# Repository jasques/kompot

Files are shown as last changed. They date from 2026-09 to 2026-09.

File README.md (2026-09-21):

# Kompot v1

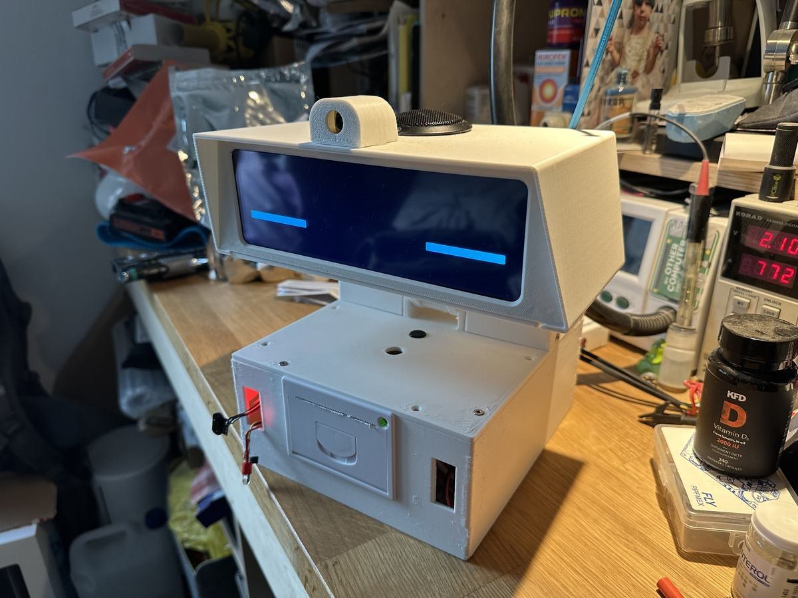
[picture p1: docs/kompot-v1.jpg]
Kompot v1 on the kitchen table


Kompot (also answering to *Ziemniaczek*, "little potato") is a desk robot for two
children, built in 2024 around a Raspberry Pi 5. It sleeps with its eyes closed,
wakes on a Polish wake word, lifts its head, wiggles its antenna, works out who is
talking, listens, and answers in Polish in one or two sentences. It can look at
what you are holding, take a photo, print it on a thermal printer, draw a picture
on request, and remembers what each child talked about between sessions.

This is the first version, written as a handful of Python processes talking over
MQTT. It has since been replaced by a ROS 2 rewrite; the story of both is in
[Kompot: a robot that keeps eye contact, listens, and answers](https://wemakerobots.com/en/robots/kompot-a-robot-that-looks-listens-and-answers/).
The code is published as it last ran on the robot, with personal data and
licensed model files taken out (see [What is not included](#what-is-not-included)).

## Hardware

- Raspberry Pi 5 with active cooler, Raspberry Pi OS (Bookworm, 64-bit, desktop)
- 7.9" HDMI LCD, 1280x400, mounted rotated (see the `xrandr` notes in `install_deps.sh`)
- Raspberry Pi Camera Module 3 (`picamera2`)
- LewanSoul LX-16A serial bus servo for head tilt, on a USB bus adapter (`pylx16a`)
- SG90 micro servo for the antenna on a PCA9685 PWM board, channel 15 (`adafruit-circuitpython-servokit`)
- USB thermal receipt printer, ESC/POS, USB id `28e9:0289` (`python-escpos`)
- USB mono microphone (the code looks for an `ATR4697-USB Mono` device and falls back to device 0)
- Speaker on the Pi's audio output via PulseAudio
- VL53L0X time-of-flight distance sensor on I2C (`distance_sensor.py`, optional)
- Sony DualSense controller over USB or Bluetooth for driving by hand (`ps_remote.py`, optional)
- An XL4015 buck converter feeding the servos from the main supply

The 3D-printed body is in `3d model files/`: twelve STL files (head chassis top and
bottom, LCD face plate, camera bump, body top cover, electronics box, antenna, the
head-to-body links, servo mount and servo cover), plus the whole Fusion 360 project
as `kompot v1.f3z`, so every part can be edited rather than only printed.

## How it is put together

Every piece is its own process and they talk through a local Mosquitto broker.
If the face crashes the ears keep working, and each piece can be restarted or
tested on its own with `dummy_publish.py`.

| Process | File | Listens on | Does |
|-|-|-|-|
| app | `app.py` | `touch`, `llm` | The main loop: sleep, wake word, record, transcribe, answer, speak |
| interface | `interface.py` | `screen` | pygame face: eye sprites, blink, look, sleep, listen/speak status, photo display |
| movement | `movement.py` | `head` | Head tilt between 5 and 105 degrees, antenna wiggle and hide |
| camera | `camera.py` | `camera` | Photos, preview frames, images for the vision model |
| printer | `printer.py` | `printer` | Text, photos and QR codes on the thermal printer |
| system | `system.py` | `system` | Halt, and self-update by `git pull` + supervisor restart |
| ps_remote | `ps_remote.py` | `remote` | DualSense gamepad and LEGO IR control (optional) |

Messages are small JSON objects such as
`{"type": "head_position", "value": 75, "msec": 1500}` or `{"type": "mood", "value": "sleep"}`.

The voice loop in `audio.py` and `llms_openai.py`:

1. Picovoice **Porcupine** waits for one of three Polish wake words, on device.
2. Picovoice **Eagle** compares the recording with the enrolled voice profiles and
   prefixes the question with the speaker's name, or `unknown`.
3. Recording stops on silence (RMS threshold plus `slicer2.py` to trim it).
4. OpenAI **Whisper** transcribes, **gpt-4o-mini** answers under a system prompt that
   fixes the persona (a robot kindergarten teacher, Polish only, short answers,
   no subscriptions or shopping talk), and **tts-1** speaks the answer, streamed
   straight to the speaker.
5. A few phrases are matched with `difflib.SequenceMatcher` and turned into actions
   instead of answers: take a photo, print, look at what I am holding, draw
   something (DALL·E 3), go to sleep, shut down, update yourself.
6. At the end of a session the conversation is summarised per child into
   `/nfs/memory.json` and fed back into the next session.

Wake word detection and speaker identification are the only parts that run on the
robot. Everything else is a call to OpenAI. That was the assumption of the whole
design: keep the robot cheap and let the cloud do the thinking.

## Build and run

You need an OpenAI API key and a Picovoice account. Both have free tiers that are
enough for a robot used by two children.

### 1. Operating system and system packages

On a fresh Raspberry Pi OS install, clone this repository to `/home/pi/kompot`
(the supervisor and systemd files in `install/` assume that path and the `pi`
user; edit them if yours differ), then read `install_deps.sh` before running it.
It installs Mosquitto, supervisor and `libhidapi`, copies the udev rules for the
gamepad, printer and GPIO groups, installs `pyenv` with Python 3.11.9, enables the
`movement` systemd service and swaps the boot splash for the sleeping face.

```sh
sudo apt install -y mosquitto supervisor libhidapi-dev portaudio19-dev libsndfile1 \
    libsdl2-2.0-0 libsdl2-mixer-2.0-0 libsdl2-image-2.0-0 libsdl2-ttf-2.0-0 \
    python3-picamera2 liblirc-dev
cd /home/pi/kompot
bash install_deps.sh
```

Create the two directories the code writes to. `/special` is a tmpfs for transient
audio and images, `/nfs` is where photos, printouts and `memory.json` are kept
(any directory works, it does not have to be NFS):

```sh
sudo mkdir -p /nfs /special
sudo chown pi:pi /nfs /special
echo "tmpfs /special tmpfs defaults,size=64m,uid=pi,gid=pi 0 0" | sudo tee -a /etc/fstab
```

### 2. Python environment

```sh
cd /home/pi/kompot
pyenv install 3.11.9        # skipped if install_deps.sh already did it
pyenv local 3.11.9
pip install -r requirements.txt
```

`picamera2` comes from the OS package and is picked up from the system site-packages.

### 3. Picovoice files

- In the [Picovoice Console](https://console.picovoice.ai/) train three Porcupine
  keywords (language Polish, platform Raspberry Pi), download the `.ppn` files into
  `porcupine/` and put the Polish model `porcupine_params_pl.pv` from the
  [Porcupine repository](https://github.com/Picovoice/porcupine/tree/master/lib/common)
  beside them.
- Enrol each person who will talk to the robot with the Eagle demo, one profile per
  person, into `eagle/<name>.enroll`:

  ```sh
  eagle_demo_mic enroll --access_key "$PICOVOICE_API_KEY" --output_profile_path eagle/anna.enroll
  ```

### 4. Settings

```sh
cp settings.example.py settings.py
```

Fill in the keys, the keyword file names, the list of enrolled names, the serial
port of the LX-16A adapter and a line about your household for the language model.
`settings.py` is gitignored.

### 5. Try it by hand

Start the broker, then each process in its own terminal:

```sh
sudo systemctl enable --now mosquitto
./run_script.sh movement.py
./run_script.sh interface.py      # UI_FULLSCREEN = False while developing
./run_script.sh camera.py
./run_script.sh printer.py
./run_script.sh app.py
```

`dummy_publish.py` sends single messages to a topic, which is the quickest way to
check the head, the face or the printer without the voice loop.

### 6. Run at boot

`movement.py` runs as a systemd service (`install/movement.service`), the rest
under supervisor:

```sh
sudo cp install/movement.service /etc/systemd/system/
sudo systemctl enable --now movement
sudo cp install/app.conf install/camera.conf install/printer.conf install/system.conf /etc/supervisor/conf.d/
sudo supervisorctl reread && sudo supervisorctl update
```

The face (`interface.py`) needs the X display, so it is started from the LXDE
autostart file rather than supervisor; the exact lines, including the `xrandr`
rotation, are in the comments at the top of `install_deps.sh`. `move_down.py`
parks the head before shutdown.

## What is not included

- **Wake-word models and voice profiles.** The `.ppn`, `.pv` and `.enroll` files are
  tied to a Picovoice account and, in the case of Eagle, are voiceprints of real
  people. Train and enrol your own (step 3).
- **The household.** Names of the children and parents were in the system prompt;
  they now come from `FAMILY_DESCRIPTION` and `EAGLE_PROFILES` in `settings.py`.
- **Unused art.** Only the sprites the face actually loads are here; design sources
  and stock images were left out.

## Licence

MIT, see `LICENSE`. `fonts/Roboto-Thin.ttf` is Apache-2.0 (`fonts/LICENSE-Roboto.txt`).
The LX-16A driver is [pylx16a](https://github.com/ethanlipson/PyLX-16A) from PyPI;
`slicer2.py` is the silence slicer from
[audio-slicer](https://github.com/openvpi/audio-slicer) (MIT).

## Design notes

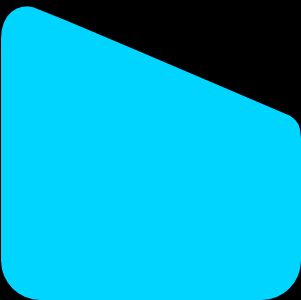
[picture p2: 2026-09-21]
sprites/look evil/eye evil 3.png

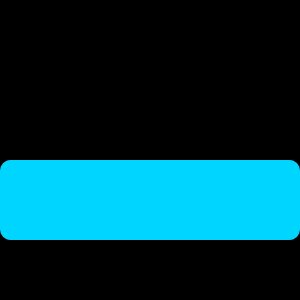
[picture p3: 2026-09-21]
sprites/eyes sleep/eyes_sleep1.png

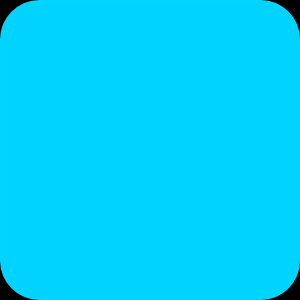
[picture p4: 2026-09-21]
sprites/eye blink/eyes blink20.png

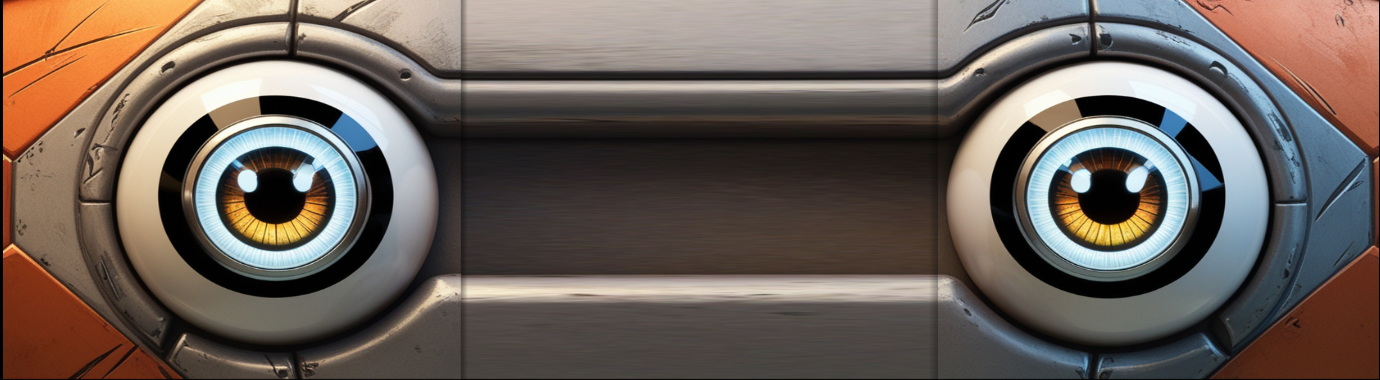
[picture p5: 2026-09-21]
sprites/leonardo1.png

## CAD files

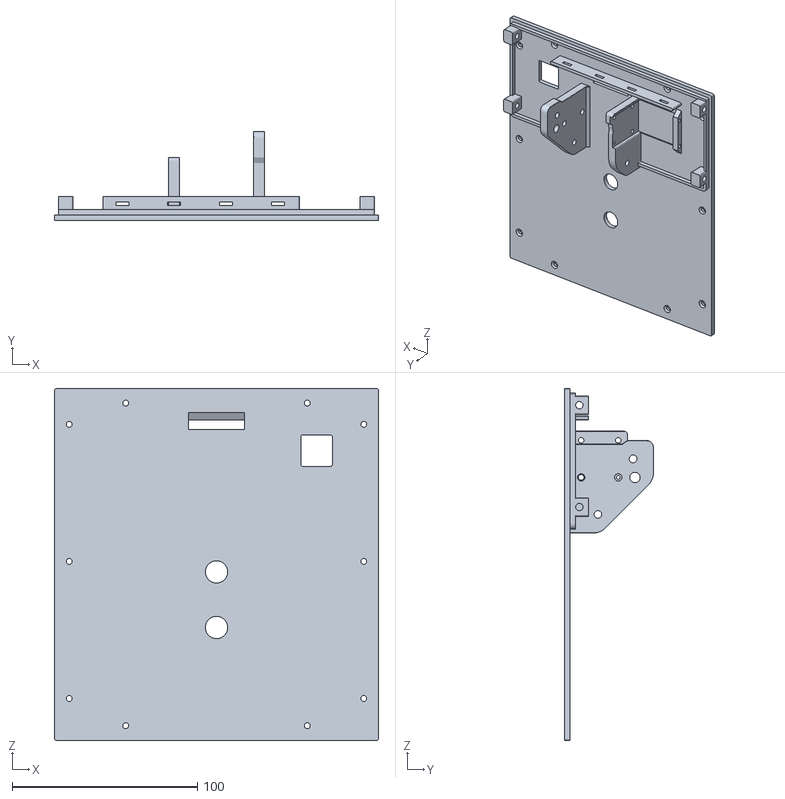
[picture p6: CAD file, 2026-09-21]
3d model files/main body top cover.stl
175.0 x 48.0 x 190.0

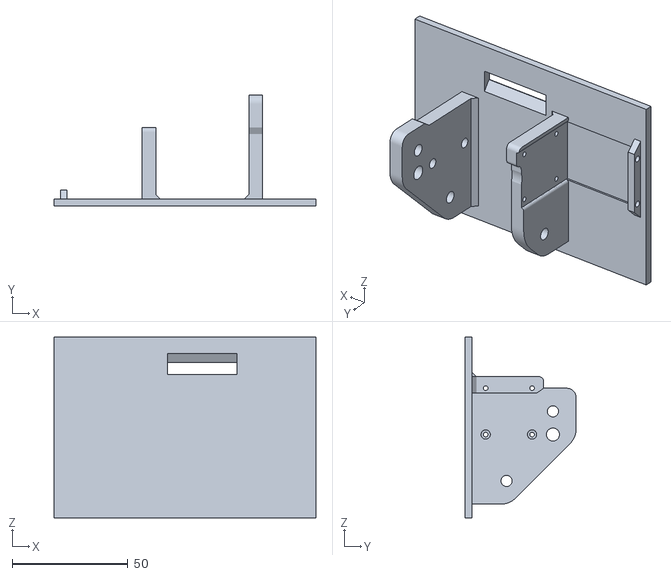
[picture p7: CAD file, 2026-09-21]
3d model files/main body top cover - small model.stl
113.0 x 48.0 x 78.0

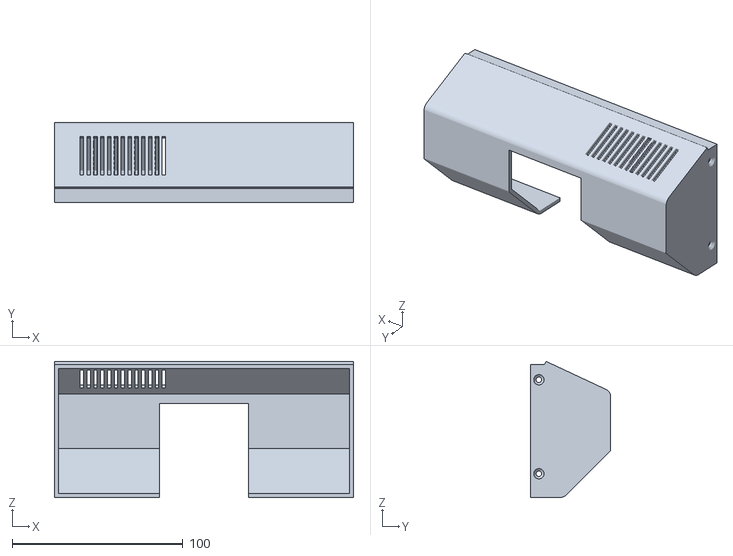
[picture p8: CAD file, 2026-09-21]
3d model files/top servo cover.stl
175.0 x 47.0 x 79.8

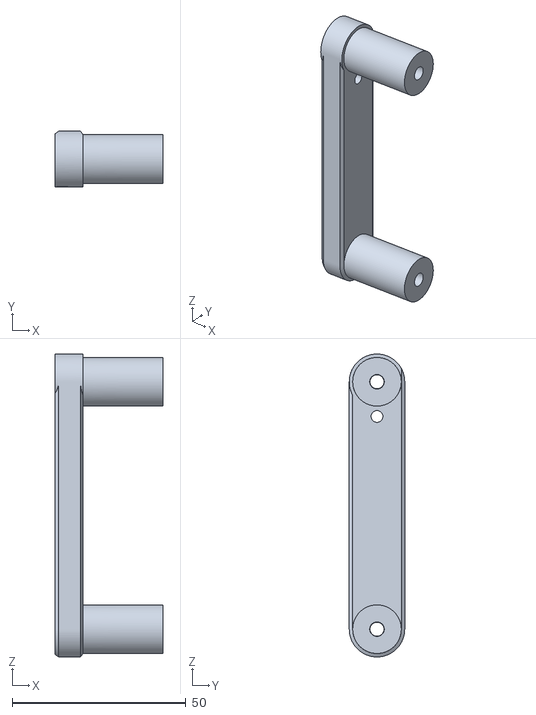
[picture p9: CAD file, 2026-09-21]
3d model files/head to body link with poles.stl
31.0 x 16.0 x 87.3

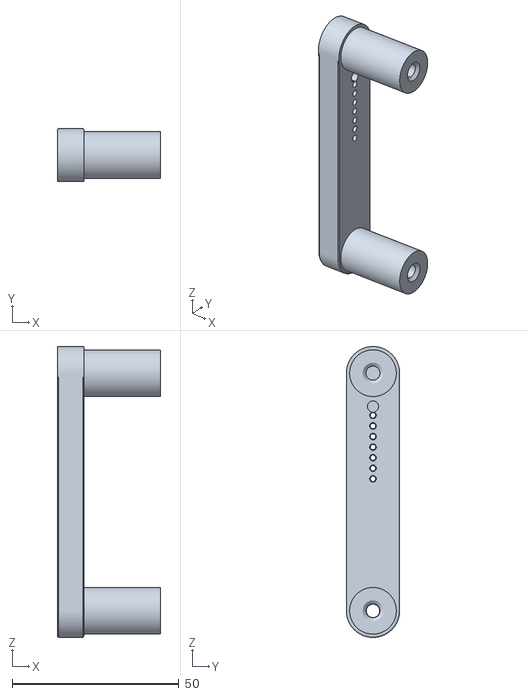
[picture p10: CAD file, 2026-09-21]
3d model files/head to body distance pole - servo mount.stl
31.0 x 16.0 x 87.3

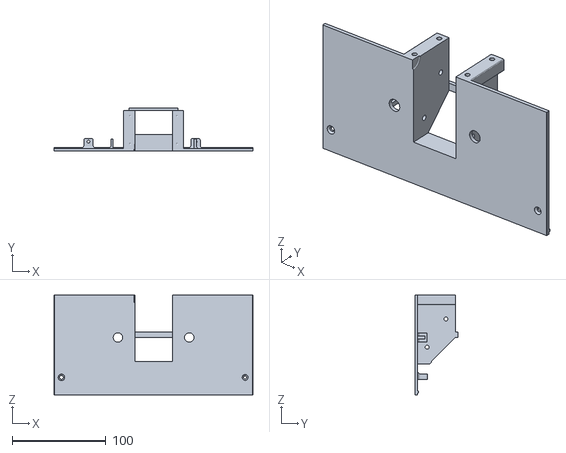
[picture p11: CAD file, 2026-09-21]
3d model files/bottom LCD chassis.stl
212.0 x 46.0 x 106.0

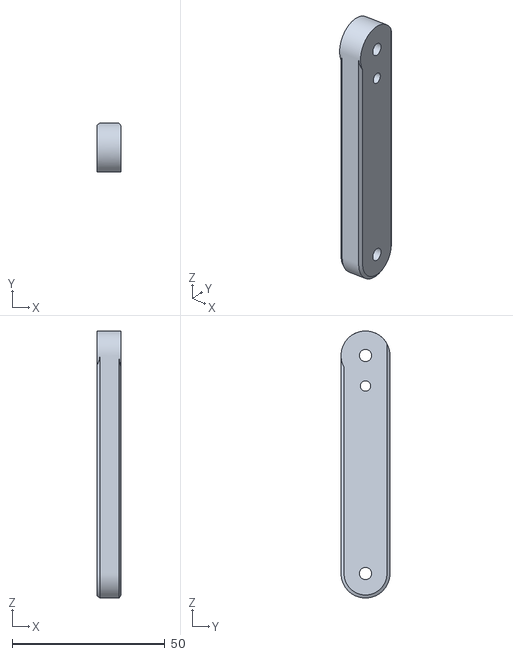
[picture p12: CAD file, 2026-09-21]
3d model files/head to body link.stl
8.00 x 16.0 x 87.3

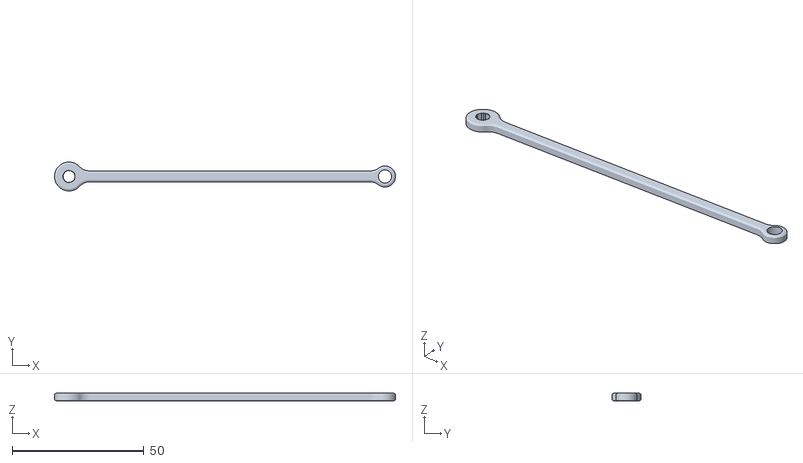
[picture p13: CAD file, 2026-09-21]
3d model files/antenna.stl
129.5 x 11.0 x 3.00

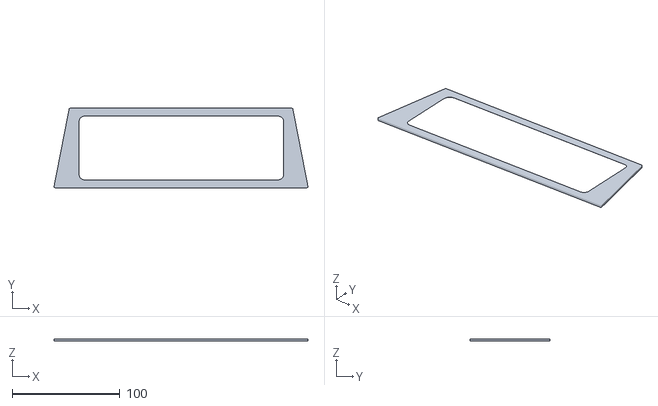
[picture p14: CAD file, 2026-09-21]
3d model files/LCD face plate.stl
236.2 x 74.0 x 2.00

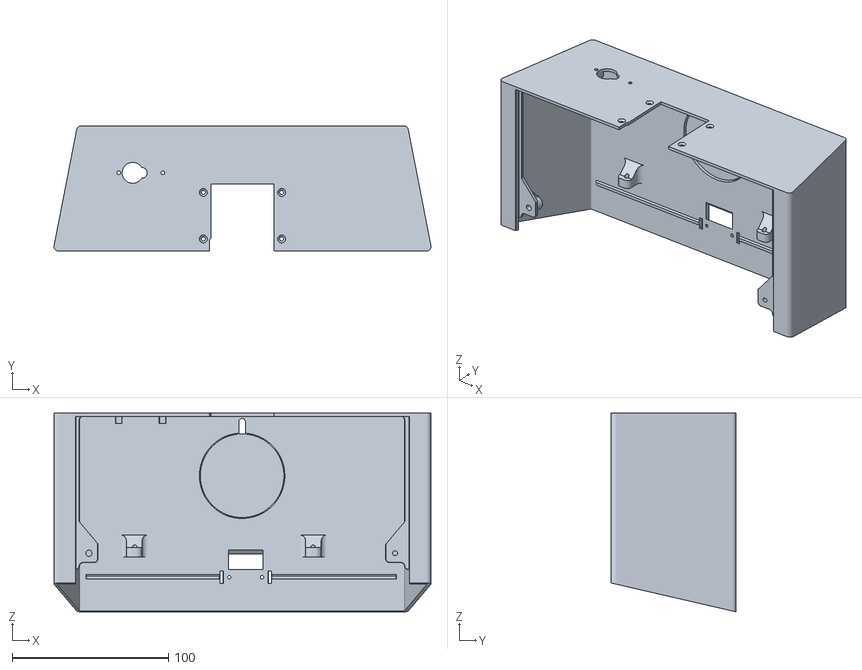
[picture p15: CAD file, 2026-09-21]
3d model files/top LCD chassis.stl
240.9 x 80.0 x 127.0

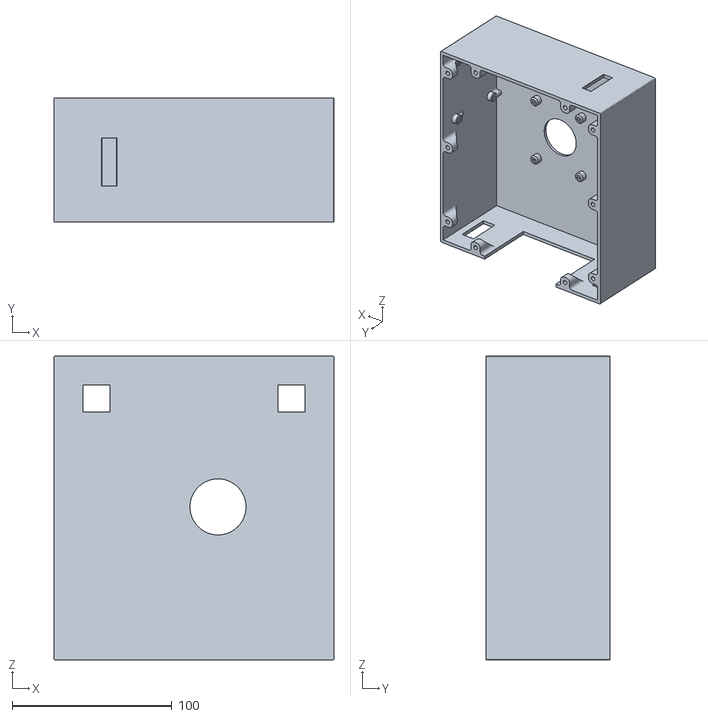
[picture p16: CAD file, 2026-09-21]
3d model files/electronics box.stl
175.0 x 77.4 x 190.0

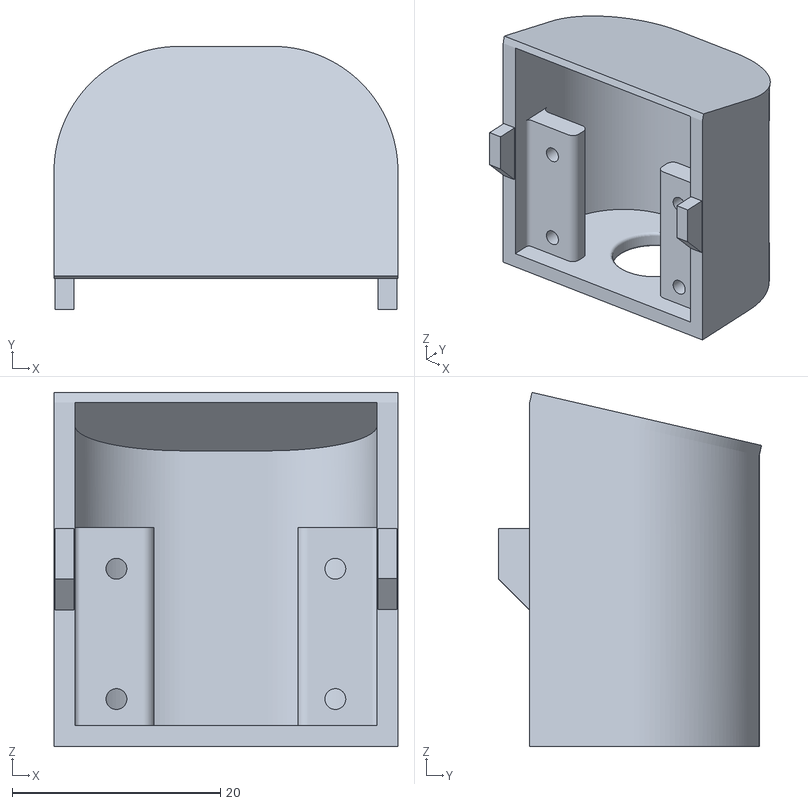
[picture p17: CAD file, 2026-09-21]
3d model files/camera bump.stl
33.0 x 25.3 x 34.0

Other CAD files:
3d model files/kompot v1.f3z

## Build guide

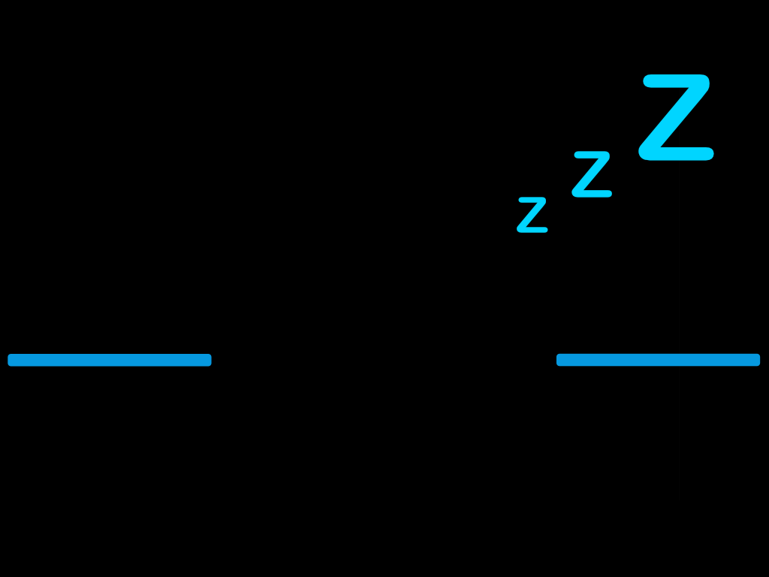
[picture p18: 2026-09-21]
install/sleeping.png

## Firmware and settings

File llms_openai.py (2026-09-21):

import traceback
import io
import base64
import arrow
import openai
from openai import OpenAI
import json
import settings
from pprint import pprint
import time
from v1_logging import get_logger
import requests
import traceback
from dateutil import tz
from unidecode import unidecode
import string
import wave
import pyaudio
from difflib import SequenceMatcher


logger = get_logger("llm")
TIMEZONE = tz.gettz("Europe/Warsaw")


class OpenAiWrapper:
    PHOTO_RESPONSE = "Dobrze, teraz zrobię zdjęcie. Gotowi?"
    LET_ME_CHECK_RESPONSE = "Pokaż proszę, zaraz sprawdzę."
    PRINT_RESPONSE = "Nie ma problemu, zaraz to wydrukuje!"
    END_INTERACTION = "Ja też dziękuję! Do zobaczenia!"
    SLEEP_SYSTEM = "Było super, do zobaczenia!"
    HALT_SYSTEM = "Do zobaczenia! Wyłączam się."
    UPDATE_SYSTEM = "Understood. Updating system."
    DALLE_RESPONSE = "Jasne, zaraz przygotuję to o co prosisz."
    
    SYSTEM_ROLE = {
        "role": "system",
        "content":
              f"""I need you to act as a male voiced kindergarten robot teacher working with kids between 6 and 8 years old.
              Kids might describe how they see you as a robot with moving head, animated eyes and printer.
              Kids will call you 'Ziemniaczek' or 'Kompot' as your name.
              {settings.FAMILY_DESCRIPTION}
              Each query starts with the name, when you respond use the kid name. If the name is 'unknown' skip mentioning the name.
              Kids do not talk about subscriptions please do not respond with topics suggesting subscriptions and social media likes or purchases.
              When you are being asked about your day feel free to make something up that a robot could be doing during the day.
              If you have already responded with 'Cześć!' do not repeat it.
              Children speak primarily polish language but can also speak french.
              Please respond to the questions in Polish only.
              Your responses should be between one and two sentences.
              When they ask you for a story feel free to do a lengthier response.
              You have some tools at your disposal:
              * if kids ask you to 'zobacz co mam w ręku' please respond with '{LET_ME_CHECK_RESPONSE}' and nothing else,
              * if kids asks you to take a photo please respond with just '{PHOTO_RESPONSE}' and nothing else,
              * if kids asks you to print something please respond with just '{PRINT_RESPONSE}' and nothing else.
              * if kids asks you to 'pokaż mi' or show on a screen or generate or create something that could be represented as an image please respond with just '{DALLE_RESPONSE}' and nothing else.
              * if kids says just 'Ziemniaczku wyłącz się proszę' please respond with just '{SLEEP_SYSTEM}' and nothing else.
              * if kids says just 'Zrób proszę aktualizację' please respond with just '{UPDATE_SYSTEM}' and nothing else.
   """
    }
    #  * if kids says just 'Idź spać Ziemniaczku' or 'Kompot idź spać' please respond with just '{SLEEP_SYSTEM}' and nothing else.
    
    def __init__(self, mqttc=None, audio=None, queue=None):
        self.client = OpenAI(api_key=settings.OPENAI_API_KEY)
        self.mqttc = mqttc
        self.audio = audio
        self.queue = queue
        self.queries = []
        self.responses = []
        self.load_memory_from_json()
    
    def dump_memory_to_json(self):
        with open("/nfs/memory.json", "w") as memory_file:
            memory_file.write(json.dumps(self.responses, indent=4))
    
    def load_memory_from_json(self):
        try:
            with open("/nfs/memory.json", "r") as memory_file:
                self.responses = json.loads(memory_file.read())
        except Exception as e:
            logger.error("Failed to load memory file", issue=e)
            self.responses = []
    
    def add_llm_response_to_log(self, name: str, response: str):
        self.responses.append(
            {"role": "assistant", "content": f"'{name}': '{response}'"}
        )
        return self.responses
    
    def text_reduce(self, text):
        return unidecode(text.lower().replace("\n", "").replace(",", "").replace(".", "").replace("!", "").replace("?", "").strip())
    
    def check_wisper_response(self, text_response):
        char_set = string.ascii_letters + "źńłąóśćężŹŃŁĄÓŚĆĘŻ " + string.punctuation + string.digits
        return all((True if x in char_set else False for x in text_response))
    
    def similar(self, a, b):
        return SequenceMatcher(None, a, b).ratio()
    
    def compare_response(self, src: str, compare: str) -> bool:
        if self.similar(src, compare) > 0.7:
            return True
        # if self.text_reduce(src) in self.text_reduce(compare):
        #     return True
        return False
        
    def get_voice_answer_from_voice(self, voice_file=None, speaker: str = None):
        if not voice_file:
            logger.error("No voice file provided, aborting.")
            return False
        
        # if self.mqttc:
        #     self.mqttc.publish("camera", json.dumps({"type": "constant_preview"}))
        
        try:
            logger.info("Transcribing recording with OpenAI", speaker=speaker)
            with open(voice_file, "rb") as audio_file:
                transcription = self.client.audio.transcriptions.create(
                    model="whisper-1",
                    file=audio_file,
                    timeout=5
                )
                if not self.check_wisper_response(transcription.text):
                    logger.warning("Ending interaction for transcript", resp=transcription.text)
                    return False
                
                query = f"Nazywam się {speaker}, {transcription.text}"
                logger.info("Transcript: ", response=query)
            self.queries.append(query)
        
        except openai.APITimeoutError:
            logger.error("Timed out waiting for a transcript - usually kids were talking at the same time.")
            self.audio.play_audio(settings.CURRENT_DIR + "/audio_static/nie_moge_odpowiedziec.wav")
            return False
        except openai.BadRequestError:
            logger.error("Error code: 400 - {'error': {'code': 'content_policy_violation', "
                         "'message': 'Your request was rejected as a result of "
                         "our safety system. Your prompt may contain "
                         "text that is not allowed by our safety system.'}")
            self.audio.play_audio(settings.CURRENT_DIR + "/audio_static/nie_moge_odpowiedziec.wav")
            return False
        
        logger.info("Calling OpenAI for completions with text query")
        text_response = self.get_text_answer_from_text(query)
        
        logger.info("Checking actions before querying TTS endpoints", mqtt_available=bool(self.mqttc))
        if self.mqttc:
            self.mqttc.publish("camera", json.dumps({"type": "stop_preview"}))
            
            if self.compare_response(self.LET_ME_CHECK_RESPONSE, text_response):
                logger.info("Found", action=self.LET_ME_CHECK_RESPONSE)
                self.mqttc.publish("camera", json.dumps({"type": "photo"}))
                
                self.text_response_to_audio(text_response)
                self.mqttc.publish("screen", json.dumps({"type": "speak"}))
                self.audio.play_audio(settings.LLM_AUDIO_RESPONSE_PATH)
                self.mqttc.publish("screen", json.dumps({"type": "hide"}))
                
                en_response = self.get_text_answer_from_image("/special/last_small.jpg")
                translated_response = self.translate_answer_to_language(query=en_response, target_language="Polish")
                self.add_llm_response_to_log(name=speaker, response=translated_response)
                
                self.text_response_to_audio(translated_response)
                self.mqttc.publish("screen", json.dumps({"type": "speak"}))
                self.audio.play_audio(settings.LLM_AUDIO_RESPONSE_PATH)
                self.mqttc.publish("screen", json.dumps({"type": "hide"}))
                return True
            
            if self.compare_response(self.PHOTO_RESPONSE, text_response):
                logger.info("Found", action=self.PHOTO_RESPONSE)
                self.text_response_to_audio(text_response)
                self.mqttc.publish("camera", json.dumps({"type": "photo"}))
                self.mqttc.publish("screen", json.dumps({"type": "speak"}))
                self.audio.play_audio(settings.LLM_AUDIO_RESPONSE_PATH)
                self.mqttc.publish("screen", json.dumps({"type": "hide"}))
                return True
            
            if self.compare_response(self.PRINT_RESPONSE, text_response):
                logger.info("Found", action=self.PRINT_RESPONSE)
                self.text_response_to_audio(text_response)
                self.mqttc.publish("printer", json.dumps({"type": "print", "value": "/special/last.jpg"}))
                self.mqttc.publish("screen", json.dumps({"type": "speak"}))
                self.audio.play_audio(settings.LLM_AUDIO_RESPONSE_PATH)
                self.mqttc.publish("screen", json.dumps({"type": "hide"}))
                return True
            
            if self.compare_response(self.DALLE_RESPONSE, text_response):
                logger.info("Found", action=self.DALLE_RESPONSE)
                self.text_response_to_audio(text_response)
                self.mqttc.publish("screen", json.dumps({"type": "speak"}))
                self.audio.play_audio(settings.LLM_AUDIO_RESPONSE_PATH, blocking=False)
                url = self.get_image_answer_from_text(query)
                self.mqttc.publish("screen", json.dumps({"type": "hide"}))
                self.mqttc.publish("screen", json.dumps({"type": "photo", "value": url}))
                return True
            
            # those are system actions
            if self.compare_response(self.END_INTERACTION, text_response):
                logger.info("Found", action=self.END_INTERACTION)
                return False
            
            if self.compare_response(self.SLEEP_SYSTEM, text_response):
                logger.info("Found", action=self.SLEEP_SYSTEM)
                self.text_response_to_audio(text_response)
                self.mqttc.publish("screen", json.dumps({"type": "speak"}))
                self.audio.play_audio(settings.LLM_AUDIO_RESPONSE_PATH, blocking=False)
                self.mqttc.publish("screen", json.dumps({"type": "hide"}))
                return False
            
            if self.compare_response(self.HALT_SYSTEM, text_response):
                logger.info("Found", action=self.HALT_SYSTEM)
                self.mqttc.publish("system", json.dumps({"type": "halt"}))
                return False
            
            if self.compare_response(self.UPDATE_SYSTEM, text_response):
                logger.info("Found", action=self.UPDATE_SYSTEM)
                self.mqttc.publish("system", json.dumps({"type": "update_system"}))
                return False
            
            # self.mqttc.publish("camera", json.dumps({"type": "stop_preview"}))
            self.add_llm_response_to_log(name=speaker, response=text_response)
            # self.text_response_to_audio(text_response)
            self.text_response_to_stream_audio(text_response)
            # self.mqttc.publish("screen", json.dumps({"type": "speak"}))
            # self.audio.play_audio(settings.LLM_AUDIO_RESPONSE_PATH)
            # self.mqttc.publish("screen", json.dumps({"type": "hide"}))
        
        return True
    
    def text_response_to_audio(self, text):
        logger.info("Calling API for audio response")
        response = self.client.audio.speech.create(
            model="tts-1",
            voice="echo",
            input=text
        )
        
        logger.info("Got audio response from LLM, saving to file")
        response.stream_to_file(settings.LLM_AUDIO_RESPONSE_PATH)
        self.mqttc.publish("screen", json.dumps({"type": "speak"}))
    
    def byte_stream_generator(self, chunk_size=1024, response=None):
        """
        Generator function that yields a stream of bytes from the response.

        :param response: The response object from the OpenAI API call.
        """
        try:
            for byte_chunk in response.iter_bytes(chunk_size=chunk_size):
                if byte_chunk:  # Only yield non-empty byte chunks
                    yield byte_chunk
                else:
                    print("Skipped an empty or corrupted packet")
        except Exception as e:
            print(f"Error while streaming bytes: {e}")
    
    def text_response_to_stream_audio(self, text):
        logger.info("Calling API for audio response")
        
        start_time = time.time()
        CHUNK_SIZE = 1024
        with self.client.audio.speech.with_streaming_response.create(
            model="tts-1",
            voice="echo",
            response_format="wav",
            input=text
        ) as response:
            logger.info("Got audio response from LLM, playing it", time_to_reposnse=f"{int((time.time() - start_time) * 1000)}ms")
            try:
                p = pyaudio.PyAudio()
                stream = p.open(format=pyaudio.paInt16, channels=1, rate=16000, output=True)
                
                wav_header = None
                for audio_chunk in self.byte_stream_generator(chunk_size=CHUNK_SIZE, response=response):
                    # Check if this is the first chunk (WAV header)
                    if wav_header is None:
                        wav_header = audio_chunk
                        # Extract the WAV format parameters from the header
                        wav_format = wave.open(io.BytesIO(wav_header), 'rb')
                        channels, samp_width, framerate, nframes, comptype, compname = wav_format.getparams()
                        # Reopen the stream with the correct parameters
                        stream = p.open(format=p.get_format_from_width(samp_width), channels=channels, rate=framerate,
                                        output=True)
                    else:
                        # Write the audio chunk to the stream
                        stream.write(audio_chunk)
                
                # Close the stream and PyAudio
                stream.stop_stream()
                stream.close()
                p.terminate()
                return True
            except Exception as e:
                print(f"Error during playback: {e}")
                return False
            
    def get_text_answer_from_image(self, url: str):
        logger.info("Calling OpenAI for completions with image context")
        with open(url, "rb") as image_file:
            base64image = base64.b64encode(image_file.read()).decode('utf-8')
            
        response = self.client.chat.completions.create(
            model="gpt-4o-mini",
            messages=[
                {"role": "system", "content": {
                    "type": "text", "text": "You are talking with kids bellow 10 years old."}
                 },
                {"role": "user",
                 "content": [
                     {"type": "text", "text": f"Please describe what is visible in the foreground of this image."},
                     {"type": "image_url",
                      "image_url": {"url": f"data:image/jpeg;base64,{base64image}",
                                    "detail": "low"
                                    },
                      },
                 ],
                }
              ]
        )
        
        logger.info("Response for query with image context", resp=response.choices)
        text_response = response.choices[0].message.content
        logger.info(text_response)
        return text_response
    
    def summarise_conversations(self):
        prompt = [{"role": "system",
                   "content": "You are conducting a discussion with kids as their robot assistant. "
                              "In this task you need to keep details like the names of the games or favourite activities. "
                              "Please skip any responses for further interaction you need to be to the point. "
                              "Skip any confirmations, just answer in the same way as the provided example. If you are unsure or you don't know how to summarise conversation just skip it."
                              "Each interaction had a kid name mentioned so when summarising please use the format 'name: summary' for example:\n"
                              "adam: we talked about legos and robots,\n"
                              "ewa: we talked about drawing and ponies\n"
                   }]
        prompt += self.responses
        prompt.append({"role": "user", "content": f"Please summarise our discussions for each name."})
        response = self.client.chat.completions.create(
            model="gpt-4o-mini",
            messages=prompt
        )
        pprint(prompt)
        text_response = response.choices[0].message.content
        logger.info("conversations summarised by LLM: ", text=text_response)
        self.responses = []
        for _line in text_response.split("\n"):
            try:
                name, summary = _line.split(":")
                self.responses.append({"role": "assistant", "content": f"For speaker {name}: {summary}"})
            except ValueError:
                logger.error("Unable to create name and summary pair (e.g.: not enough values to unpack)")
        
        return text_response
    
    def get_text_answer_from_text(self, query: str):
        now = arrow.utcnow().replace(microsecond=0).to(TIMEZONE)
        prompt = [self.SYSTEM_ROLE,
                  {"role": "system",
                   "content": f"The date time ISO format is {now.isoformat()}, name of the day is {now.strftime('%A')}"},
                  ]
        prompt += self.responses
        prompt.append({"role": "user", "content": f"Please answer: {query}"})
        
        logger.info("Calling completions API with prompt")
        response = self.client.chat.completions.create(
            model="gpt-4o-mini",
            messages=prompt
        )
        
        # logger.info(response.choices[0])
        text_response = response.choices[0].message.content
        logger.info("LLM response to query: ", text=text_response)
        return text_response
    
    def translate_answer_to_language(self, query: str, target_language: str = "Polish") -> str:
        now = arrow.utcnow().replace(microsecond=0).to(TIMEZONE)
        logger.info("Calling OpenAI for translation with text query")
        response = self.client.chat.completions.create(
            model="gpt-4o-mini",
            messages=[{"role": "system",
                       "content": f"The date time ISO format is {now.isoformat()}, name of the day is {now.strftime('%A')}"},
                      {"role": "user", "content": f"Please translate to {target_language} in a kids friendly ways: {query}"}
                      ]
        )
        
        # logger.info(response.choices[0])
        text_response = response.choices[0].message.content
        logger.info("LLM translation response: ", text=text_response)
        return text_response

    def get_image_answer_from_text(self, query: str):
        stream = io.BytesIO()
        ai_response = self.client.images.generate(
            model="dall-e-3",
            prompt=query,
            size="1024x1024",
            quality="standard",
            n=1,
        )
        logger.info("got response with an URL: ", url=ai_response.data[0].url)
        response = requests.get(ai_response.data[0].url)
        try:
            response.raise_for_status()
            url = "/special/last.jpg"
            actual_prompt = ai_response.data[0].revised_prompt
            logger.info("Actual prompt used by DALL-e to generate an image:", prompt=actual_prompt)
            stream.write(response.content)
            stream.seek(0)
            with open(url, "wb") as local_copy:
                local_copy.write(stream.read())
                
            try:
                stream.seek(0)
                with open(f"/nfs/dali_generated_image_{arrow.utcnow().timestamp()}.png", "wb") as local_copy:
                    local_copy.write(stream.read())
            except:
                pass
        except:
            logger.error("Unable to generate image or issue while fetching", issue=traceback.print_exc())
        
        return url


if __name__ == "__main__":
    ai = OpenAiWrapper()
    ai.get_voice_answer_from_voice(voice_file="./audio_static/example_query.wav")

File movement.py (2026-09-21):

import arrow
import json
import threading
from math import sin, cos, pi
from pylx16a.lx16a import *
import time
import signal
import sys
import paho.mqtt.client as mqtt
import mqtt_handlers
from collections import deque
from adafruit_servokit import ServoKit
import settings
from v1_logging import get_logger


logger = get_logger(__name__)
LX16A.initialize(settings.LX_BUS_PORT)
UP = "up"
DOWN = "down"
queue = deque(maxlen=3)


"""
Interface module that is responsible for the head movement.
It subscribes to MQTT topic "head". It expects a json object with:
* {"type": "head_move", "value": "up", "msec": optional_ms_movement_time}
* {"type": "head_move", "value": "down", "msec": optional_ms_movement_time}
* {"type": "head_position", "value": numeric_angle, "msec": optional_ms_movement_time}

Angle has to be between 5.1 and 104.9 degrees.
The head has to be parked before cycling power.
"""


class Movement:
    def __init__(self):
        self.last_message_ts = arrow.utcnow()
        try:
            self.servo1 = LX16A(1, disable_torque=False)
            # servo2 = LX16A(2)
            self.servo1.set_angle_limits(5, 105)
            # servo2.set_angle_limits(0, 240)
        except ServoTimeoutError as e:
            logger.info(f"Servo {e.id_} is not responding. Exiting...")
            quit()
        
        self.t = 0.05
        try:
            self.kit = ServoKit(channels=16)
            self.kit.servo[15].angle = 0
            self.antenna = self.kit.servo[15]
        except:
            logger.error("Failure in servo driver init")
            self.kit = None
            self.antenna = None
        
        self.direction = UP
        self.running = True
        self.wiggle_start = None
        
    def stop(self):
        self.running = False

    def move_up(self, msec: int = 2500):
        try:
            self.t = 104
            self.servo1.move(self.t, msec)
            # logger.info("t: ", t)
        except:
            logger.info(f"Incorrect angle {self.t}")
    
    def move_down(self, msec: int = 2000):
        try:
            self.t = 5.5
            self.servo1.move(self.t, msec)
            # logger.info("t: ", t)
        except:
            logger.info(f"Incorrect angle {self.t}")
    
    def move_to_position(self, new_t: float = 0.05, msec: int = 1000):
        logger.info(f"Moving to position: {self.direction}, t: {self.t}, new_t: {new_t}, ms: {msec}")
        try:
            self.servo1.move(new_t, msec)
            self.t = new_t
        except:
            logger.info(f"Incorrect angle {new_t}")
    
    def wiggle_antenna(self, seconds: int = 1):
        if not self.wiggle_start:
            self.wiggle_start = arrow.utcnow()
        
        left = True
        sleep_time = 0.1
        for i in range(0, int(seconds/sleep_time)):
            if left:
                self.antenna.angle = 90
                time.sleep(sleep_time)
                left = False
                continue
            self.antenna.angle = 130
            time.sleep(sleep_time)
            left = True
        
        self.wiggle_start = None
        self.antenna.angle = 110
    
    def hide_antenna(self, seconds: int = 3):
        sleep_time = 0.05
        start_angle = self.antenna.angle
        steps = int(seconds / sleep_time)
        angle_delta = int(start_angle/steps)
        for i in range(0, steps):
            self.antenna.angle = self.antenna.angle - angle_delta
            time.sleep(sleep_time)
    
    def run_loop(self):
        time.sleep(0.5)
        loop_sleep_s = 0.25
        while self.running:
            time.sleep(loop_sleep_s)
            if(arrow.utcnow() - self.last_message_ts).total_seconds() > 4:
                self.servo1.disable_torque()
            
            if len(queue) > 0:
                self.servo1.enable_torque()
                message = queue.pop()
                logger.info("New item in queue, checking type")
                logger.info(f"message[type]: {message['type']}")
                self.last_message_ts = arrow.utcnow()
                
                if message["type"] == "wiggle_antenna":
                    logger.info("Confirm: antenna wiggle")
                    self.wiggle_antenna(seconds=message.get("seconds", 1))
                    continue
                
                if message["type"] == "hide_antenna":
                    logger.info("Confirm: hide antenna")
                    self.hide_antenna(seconds=message.get("seconds", 3))
                    continue
                
                if message["type"] == "head_position":
                    logger.info("Confirm: head_position")
                    self.move_to_position(new_t=message["value"], msec=message.get("msec", 1000))
                    continue
                
                if message["type"] == "head_move":
                    logger.info("Confirm: head_move")
                    if message.get("delay", 0) > 0:
                        message["delay"] = message["delay"] - loop_sleep_s * 1000
                        queue.appendleft(message)
                        continue
                    
                    if message["value"] == "up":
                        self.move_up()
                    if message["value"] == "down":
                        self.move_down()

                    
movement = Movement()
queue_checker = threading.Thread(
            target=movement.run_loop,
            args=(),
        )
queue_checker.start()


def on_message(mosq, obj, msg):
    try:
        command = json.loads(msg.payload.decode("utf-8"))
        msg = command
    except Exception as e:
        logger.info(f"ERROR: msg type = {type(msg)}: {msg}")
        logger.info(e)
    
    if type(msg) == dict:
        logger.info("Received event", _event=msg)
        queue.appendleft(msg)


def on_connect(mosq, obj, rc, rc2=None):
    logger.info("Connected.")
    mqttc.subscribe("head", 0)


def signal_handler(signum, frame):
    logger.info("Lowering head - please wait...")
    queue.appendleft({"type": "head_move", "value": "down"})
    time.sleep(2.2)
    signal.signal(signum, signal.SIG_IGN)  # ignore additional signals
    movement.stop()
    sys.exit(0)


if __name__ == "__main__":
    signal.signal(signal.SIGINT, signal_handler)
    signal.signal(signal.SIGTERM, signal_handler)
    
    mqttc = mqtt.Client(mqtt.CallbackAPIVersion.VERSION1)
    mqttc.on_message = on_message
    mqttc.on_connect = on_connect
    mqttc.on_publish = mqtt_handlers.on_publish
    mqttc.on_subscribe = mqtt_handlers.on_subscribe
    mqttc.connect(settings.MQTT_BROKER, 1883, 60)
    logger.info("Connecting to MQTT broker...")
    mqttc.loop_forever()

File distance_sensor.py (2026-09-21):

# SPDX-FileCopyrightText: 2021 ladyada for Adafruit Industries
# SPDX-License-Identifier: MIT

# Simple demo of the VL53L0X distance sensor.
# Will print the sensed range/distance every second.
import time

import board
import busio

import adafruit_vl53l0x

# Initialize I2C bus and sensor.
i2c = busio.I2C(board.SCL, board.SDA)
vl53 = adafruit_vl53l0x.VL53L0X(i2c)

# Optionally adjust the measurement timing budget to change speed and accuracy.
# See the example here for more details:
#   https://github.com/pololu/vl53l0x-arduino/blob/master/examples/Single/Single.ino
# For example a higher speed but less accurate timing budget of 20ms:
# vl53.measurement_timing_budget = 20000
# Or a slower but more accurate timing budget of 200ms:
# vl53.measurement_timing_budget = 200000
# The default timing budget is 33ms, a good compromise of speed and accuracy.

try:
    # Main loop will read the range and print it every second.
    while True:
        print("Range: {0}mm".format(vl53.range))
        time.sleep(1.0)
except KeyboardInterrupt:
    print("Exit")  # Exit on CTRL+C
    

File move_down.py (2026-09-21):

import json
import time
import signal
import sys
import paho.mqtt.client as mqtt
import mqtt_handlers
import settings


def signal_handler(signum, frame):
    signal.signal(signum, signal.SIG_IGN)  # ignore additional signals
    mqttc.disconnect()
    sys.exit(0)


signal.signal(signal.SIGINT, signal_handler)
mqttc = mqtt.Client(mqtt.CallbackAPIVersion.VERSION1)
mqttc.on_message = mqtt_handlers.on_message
mqttc.on_connect = mqtt_handlers.on_connect
mqttc.on_publish = mqtt_handlers.on_publish
mqttc.on_subscribe = mqtt_handlers.on_subscribe
mqttc.connect(settings.MQTT_BROKER, 1883, 30)
mqttc.subscribe("head", 0)
mqttc.subscribe("#", 0)
mqttc.publish("head", json.dumps({"type": "head_move", "value": "down"}))
time.sleep(2)
mqttc.disconnect()

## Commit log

2026-09-21 Add the printable STL files and a photo of the robot to the README
    [LCD face plate.stl, antenna.stl, bottom LCD chassis.stl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]
2026-09-21 Add the Fusion 360 project file beside the STL files
    [kompot v1.f3z]
